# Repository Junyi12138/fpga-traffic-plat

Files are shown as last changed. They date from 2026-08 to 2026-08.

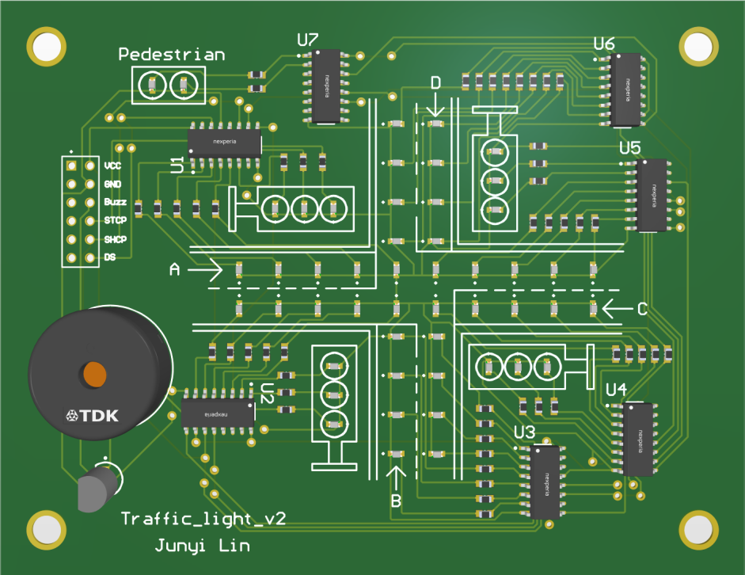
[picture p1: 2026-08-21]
hardware/pcb.png

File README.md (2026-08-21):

# fpga-traffic-plat
FPGA-based traffic light evaluation platform — plug in different control strategies and compare them using real per-vehicle statistics, rather than watching if a set of lights looks right.

This started as an MSc dissertation project at the University of Edinburgh (School of Engineering). It runs on a low-cost FPGA connected to a Raspberry Pi, and is built for two teaching uses: showing a control strategy running live on physical hardware, and letting an instructor define custom traffic scenarios to evaluate a student's control algorithm using real journey/wait-time statistics rather than simulation.

## Hardware

- iCE40HX1K FPGA (ice4pi board)
- Raspberry Pi 4, connected over the 40-pin GPIO header
- Custom PCB: four-direction LED junction, driven by seven 74HC595 shift registers

## Getting Started

1. **Physical connection.** Plug the ice4pi board onto the Raspberry Pi's 40-pin GPIO header.
2. **Connect to the Pi.** Over SSH from another machine, or directly with a keyboard/monitor attached. Enable SPI first (sudo raspi-config → Interface Options → SPI) — this is what lets the Pi flash and talk to the FPGA. Also free up /dev/ttyAMA0 for the FPGA's UART connection: disable Bluetooth (sudo raspi-config → Interface Options → Serial Port → disable) and disable the login shell over serial (same menu, separate option) — both independently claim this interface, and disabling only one still leaves the connection unreliable. If statistics transmission is still flaky after both are off, check for any other process still holding /dev/ttyAMA0 open (e.g. sudo lsof /dev/ttyAMA0) and kill it.
3. **Install the toolchain.**
   sudo apt install git yosys fpga-icestorm arachne-pnr flashrom
4. **Get ice4pi_prog.** Clone the official board repo and keep the example/ folder's ice4pi_prog file for the next step:
   git clone https://github.com/lightside-instruments/ice4pi.git
5. **Create one working folder on the Pi**, and copy everything into it: every `.v` file, `top.pcf`, `ice4pi_prog` (from step 4), the Makefile, and the Python scripts from this repo's `verilog/` and `python/` folders. They all need to sit together, flat, in this one folder — the Makefile and `test_runner.py` both use relative paths and won't find anything split across separate directories. `traffic_light_extend.v`, `traffic_light_sensor.v`, and `traffic_light_timer.v` all declare the same internal module, `traffic_light_extend` — this is intentional, not a naming mistake, since it's what lets switching control strategies work by swapping a single file. Only one of these three can be present at a time, or the toolchain will fail with a duplicate module definition error.
6. **Build and flash:**

make
sudo make load

## Repository structure

Assumes you're working on the Raspberry Pi (over SSH from another machine, or directly) with the ice4pi board plugged into the Pi's 40-pin header and SPI enabled — that connection is what lets the Pi flash and communicate with the FPGA in the first place.

- `verilog/` — all FPGA source: `top.v`, `road_control.v` / `road_control_lite.v` (full-statistics and lite variants), `calculator.v`, three example control strategies (`traffic_light_timer.v`, `traffic_light_sensor.v`, `traffic_light_extend.v` for combine — all three declare the same internal module, `traffic_light_extend`, intentionally, so only one can be present in the build folder at a time), `hc595_serializer.v`, `buzzer_gate.v`, `frame_clk_div.v`, `stat_reporter.v`, `uart_tx.v`, and the pin constraint file `top.pcf`
- `python/` — test automation: `test_config.py` defines the traffic density/road-type test matrix, `test_runner.py` drives the hardware and records results
- Note: `verilog/` and `python/` are separated here for browsing on GitHub only. On the Raspberry Pi itself, everything — all Verilog source files, `top.pcf`, `ice4pi_prog`, and the Python scripts — should sit together in one working directory; the Makefile and `test_runner.py` both expect relative paths within that single folder, not the split structure shown above.

hardware/ — PCB design files (Traffic_light_v2) and the full bill of materials

## Building and flashing

Toolchain: ice4pi open-source flow (yosys, arachne-pnr, icepack, flashed via ice4pi_prog). ice4pi_prog comes from the official lightside-instruments/ice4pi repository, in its example/ folder alongside the sample Makefile — clone that repo and copy ice4pi_prog from there if it's missing from this project.

sudo apt install git yosys fpga-icestorm arachne-pnr flashrom

To switch which control strategy is running, copy the desired variant into the project as traffic_light_extend.v. The whole project folder — every file listed in the Makefile, top.pcf, and the ice4pi_prog executable — must be present and named exactly as-is; the load step calls ./ice4pi_prog by relative path and won't run without it.

make
sudo make load

## Running an evaluation

Traffic density and road type are set in `test_config.py` as plain Python values (`BASE_INTERVAL`, `MINOR_MULTIPLIER`). Edit these, then run `test_runner.py` to generate a new set of test combinations. Each run produces a timestamped CSV with car count, journey/wait time (total and max), and throughput per direction. 

## Manual demo (classroom use)

demo.py is a simple interactive control panel for live demonstration — not for running the automated 27-combination evaluation (test_runner.py does that). It lets you manually pulse a single car into any direction, trigger the pedestrian button, or reset the FPGA, one command at a time from the terminal:

python3 demo.py

Then type a/b/c/d to send one car to that direction, p for a pedestrian request, r to reset, or q to quit. Useful for showing a control strategy running live on the hardware without setting up a full test run.

## Writing a control strategy

A control strategy is a single Verilog module, `traffic_light_extend`, and nothing outside it needs to be touched. It must accept `clk_12mhz`, `rst`, `Sa`, `Sb` (merged sensor inputs for the two direction pairs), `Pb` (pedestrian button), and drive `Ga`/`Ya`/`Ra`, `Gb`/`Yb`/`Rb`, `Gp`/`Rp`. The port list must stay exactly as-is even if a design doesn't use every signal — leave unused inputs unread, and tie unused outputs to a constant (e.g. `assign Gp = 1'b0;`) rather than dropping the port.

The current interface only supports strategies that treat the junction as two direction pairs (AC and BD together); it cannot express four independently-controlled directions without also changing `top.v`.

## Known limitations

- Each control strategy was evaluated once per test combination in the accompanying thesis, not repeated — some results reflect single-run timing variation, not a robust average.
- `calculator.v`'s BRAM read has a known timing edge case: under back-to-back vehicle completions, it can read the previous vehicle's entry timestamp instead of the current one's, slightly misattributing journey time in dense traffic. Not yet fixed.
- The web-based remote-access layer that originally motivated this project (students uploading code and watching it run over the internet) was not built.

## License

MIT — see LICENSE.

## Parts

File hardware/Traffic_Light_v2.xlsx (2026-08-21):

Line # | Name | Description | Designator | Quantity | Manufacturer 1 | Manufacturer Part Number 1 | Manufacturer Lifecycle 1 | Supplier 1 | Supplier Part Number 1 | Supplier Unit Price 1 | Supplier Subtotal 1 | JLCPCB Part
 | KT-0603W | White 0603 Light Emitting Diodes | A0, A1, A2, A3, A4, A5, A6, A7, A8, A9, B0, B1, B2, B3, B6, B7, B8, B9, C0, C1, C2, C3, C4, C5, C6, C7, C8, C9, D0, D1, D2, D3, D6, D7, D8, D9 | 36 |  |  |  |  |  |  |  | C2290
 | KT-0603G | Green 0603 Light Emitting Diodes | GA, GB, GC, GD, GP | 5 |  |  |  |  |  |  |  | C12624
 | PS1720P02 | AUDIO PIEZO TRANSDUCER 30V TH | LS1 | 1
 | TSW-106-07-T-D | TSW - Samtec 2.54mm Pin Header 10.92mm Overall Pin Length (07) - Fast Stock | P1 | 1 | Samtec | TSW-106-07-T-D | Volume Production | RS | 1802231 | 0.78377 | 7.84
 | BS170 | Small Signal MOSFET, 500 mA, 60 V, N-Channel, 3-Pin TO-92, Bulk Box | Q1 | 1
 | Res1 | resistor | R1, R2, R3, R4, R5, R6, R7, R8, R9, R10, R11, R12, R13, R14, R15, R16, R17, R18, R19, R20, R21, R22, R23, R24, R25, R26, R27, R28, R29, R30, R31, R32, R33, R34, R35, R36, R37, R38, R39, R40, R41, R42, R43, R44, R45, R46, R47, R48, R49, R50 | 50 |  |  |  | Farnell | CFR-25JB-52-270R |  |  | C22966
 | KT-0603R | Red 0603 Light Emitting Diodes | RA, RB, RC, RD, RP | 5 |  |  |  |  |  |  |  | C2286
 | 74HC595D,118 | IC SHIFT REGISTER 8BIT 16SOIC | U1, U2, U3, U4, U5, U6, U7 | 7 |  |  |  |  |  |  |  | C5947
 | KT-0603Y | Yellow 0603 Light Emitting Diodes | YA, YB, YC, YD | 4 |  |  |  |  |  |  |  | C2287

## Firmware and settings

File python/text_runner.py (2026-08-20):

#!/usr/bin/env python3
import time
import threading
import struct
import csv
import serial
import RPi.GPIO as GPIO   # switch this if demo.py uses a different library (e.g. gpiozero)
from datetime import datetime
from test_config import TEST_MATRIX

# ============ parameters to confirm against actual wiring ============
PIN_RST         = 17
PIN_START_A     = 27
PIN_START_B     = 5
PIN_START_C     = 6
PIN_START_D     = 13
PIN_READ_STATS  = 18
PIN_PB          = 22

SERIAL_PORT = '/dev/serial0'
BAUD_RATE   = 9600

# Use 1 minute first to confirm the whole pipeline works, then switch to
# 900 (15 minutes) for the real run
TEST_DURATION_SEC = 900

OUTPUT_CSV = f"results_{datetime.now().strftime('%Y%m%d_%H%M%S')}.csv"

PULSE_WIDTH = 0.05   # 50ms, kept consistent with demo.py


def setup_gpio():
    GPIO.setmode(GPIO.BCM)
    for pin in [PIN_RST, PIN_START_A, PIN_START_B, PIN_START_C, PIN_START_D, PIN_READ_STATS, PIN_PB]:
        GPIO.setup(pin, GPIO.OUT, initial=GPIO.LOW)


def pulse(pin, width=PULSE_WIDTH):
    GPIO.output(pin, GPIO.HIGH)
    time.sleep(width)
    GPIO.output(pin, GPIO.LOW)


def reset_fpga():
    pulse(PIN_RST)
    time.sleep(0.1)   # give the FPGA a moment to finish resetting


def traffic_worker(pin_pair, interval, stop_event):
    """Every `interval` seconds, pulse start on a direction pair (AC or BD)
    together, until stop_event is set."""
    while not stop_event.is_set():
        for pin in pin_pair:
            GPIO.output(pin, GPIO.HIGH)
        time.sleep(PULSE_WIDTH)
        for pin in pin_pair:
            GPIO.output(pin, GPIO.LOW)
        stop_event.wait(interval - PULSE_WIDTH)


def parse_line(raw):
    if raw is None or len(raw) != 12 or raw[11] != 0x0A:
        return None
    direction = chr(raw[0])
    car_count, total_journey, max_journey, total_wait, max_wait = struct.unpack('>5H', raw[1:11])
    avg_wait = (total_wait / car_count) if car_count > 0 else None
    return {
        'direction': direction,
        'car_count': car_count,
        'total_journey_time': total_journey,
        'max_journey_time': max_journey,
        'total_wait_time': total_wait,
        'max_wait_time': max_wait,
        'avg_wait_time': avg_wait,
        'throughput': car_count / TEST_DURATION_SEC,
    }


def read_two_lines(ser):
    """Read a larger chunk and actively search it for the A and B lines,
    rather than assuming they start exactly at byte 0."""
    raw = ser.read(60)   # read extra so a few stray leading bytes are still fine

    idx_a = None
    for i in range(len(raw) - 11):
        if raw[i] == ord('A') and raw[i+11] == 0x0A:
            idx_a = i
            break

    idx_b = None
    if idx_a is not None:
        for i in range(idx_a + 12, len(raw) - 11):
            if raw[i] == ord('B') and raw[i+11] == 0x0A:
                idx_b = i
                break

    line_a = raw[idx_a:idx_a+12] if idx_a is not None else None
    line_b = raw[idx_b:idx_b+12] if idx_b is not None else None
    return line_a, line_b, raw


def run_one_test(combo, ser):
    reset_fpga()

    stop_event = threading.Event()
    t_ac = threading.Thread(target=traffic_worker, args=((PIN_START_A, PIN_START_C), combo['ac_interval'], stop_event))
    t_bd = threading.Thread(target=traffic_worker, args=((PIN_START_B, PIN_START_D), combo['bd_interval'], stop_event))
    t_ac.start()
    t_bd.start()

    time.sleep(TEST_DURATION_SEC)

    stop_event.set()
    t_ac.join()
    t_bd.join()

    time.sleep(0.3)   # a little margin for the threads to wind down

    ser.reset_input_buffer()
    pulse(PIN_READ_STATS)

    line_a, line_b, raw = read_two_lines(ser)

    print(f"    [debug] received {len(raw)} raw bytes: {raw!r}")
    print(f"    [debug] line_a: {line_a!r}")
    print(f"    [debug] line_b: {line_b!r}")

    return parse_line(line_a), parse_line(line_b)


def main():
    setup_gpio()
    ser = serial.Serial(SERIAL_PORT, BAUD_RATE, timeout=5)

    fieldnames = ['density', 'road_type', 'direction',
                  'car_count', 'total_journey_time', 'max_journey_time', 'total_wait_time',
                  'max_wait_time', 'avg_wait_time', 'throughput']

    with open(OUTPUT_CSV, 'w', newline='') as f:
        writer = csv.DictWriter(f, fieldnames=fieldnames)
        writer.writeheader()

        for combo in TEST_MATRIX:
            print(f"running combination: {combo['density']} / {combo['road_type']} ...")
            result_a, result_b = run_one_test(combo, ser)

            for result in (result_a, result_b):
                if result is None:
                    print("  warning: failed to parse this row, skipping")
                    continue
                row = {'density': combo['density'], 'road_type': combo['road_type']}
                row.update(result)
                writer.writerow(row)
                f.flush()

            print(f"  done: A={result_a}, B={result_b}")

    ser.close()
    GPIO.cleanup()
    print(f"all done, results saved to {OUTPUT_CSV}")


if __name__ == '__main__':
    main()

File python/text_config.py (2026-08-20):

# test_config.py
# Of the 27 combinations, the 9 traffic patterns (3 densities x 3 road
# types) are defined here. The control-model dimension is switched
# manually and isn't handled here.

BASE_INTERVAL = {
    'light':  5.0,   # seconds per vehicle duration
    'medium': 2.5,
    'heavy':  1.0,
}

MINOR_MULTIPLIER = 2   # minor road's multiplier relative to the major road

def build_test_matrix():
    """(density, road_type) -> ac_interval / bd_interval
    AC is always the major road, BD is always the minor road (only this
    asymmetric pairing is tested, not the reverse)."""
    matrix = []
    for density, base in BASE_INTERVAL.items():
        for road_type in ['major-major', 'major-minor', 'minor-minor']:
            if road_type == 'major-major':
                ac_mult, bd_mult = 1, 1
            elif road_type == 'minor-minor':
                ac_mult, bd_mult = MINOR_MULTIPLIER, MINOR_MULTIPLIER
            else:  # major-minor
                ac_mult, bd_mult = 1, MINOR_MULTIPLIER

            matrix.append({
                'density': density,
                'road_type': road_type,
                'ac_interval': base * ac_mult,
                'bd_interval': base * bd_mult,
            })
    return matrix

TEST_MATRIX = build_test_matrix()
